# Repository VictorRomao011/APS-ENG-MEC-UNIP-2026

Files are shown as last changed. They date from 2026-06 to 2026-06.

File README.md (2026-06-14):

# APS Eng. Mecânica UNIP 2026 — Elevador em Escala Reduzida

🔗 **Tour virtual 3D (publicado):** https://victorromao011.github.io/APS-ENG-MEC-UNIP-2026/

> Atividade Prática Supervisionada (APS) — Engenharia Mecânica
> Universidade Paulista (UNIP) · Instituto de Ciências e Tecnologia (ICET) · Campus Jundiaí
> APS 2026/1 — **Equipe Altus**: *"Elevando segurança, precisão e inovação"*

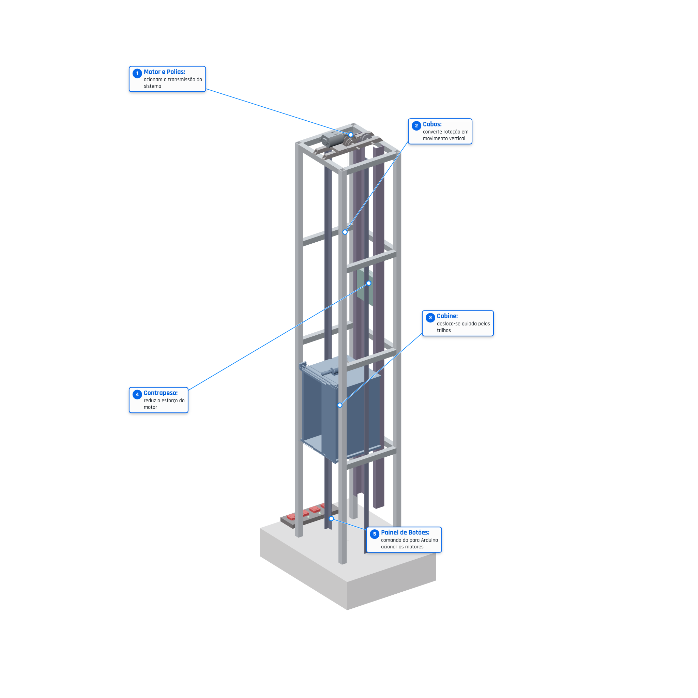
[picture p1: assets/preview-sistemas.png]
Elevador - sistemas principais


## Sobre o projeto

Protótipo funcional de **elevador em escala reduzida**, com transmissão por cabos, polias,
contrapeso e acionamento elétrico, totalmente modelado em ambiente 3D (FreeCAD) e
apresentado através de um **tour virtual interativo 360°** rodando direto no navegador
(Three.js), sem necessidade de instalar nenhum software de CAD.

O modelo é composto por **23 componentes principais**, com memorial técnico completo de
dimensionamento (estrutural, torque, potência, transmissão, cabos e estabilidade).

## Equipe Altus

- Victor Romão
- Gabriela Ferraz
- Mikael Campos
- Vitória Cristina
- Pedro Pelline
- Laura Casadei

## Tour virtual 3D

O arquivo `index.html` é um visualizador 3D autocontido (Three.js r128) que carrega a malha
do modelo CAD exportado do FreeCAD e permite:

- Rotação livre do modelo (orbit controls customizados) e vistas pré-definidas (Frontal,
  Lateral, Superior, Isométrica);
- Modo **explodido** (separa os componentes para visualizar a montagem);
- Modo com **medidas/cotas** sobre o modelo;
- Exportação de imagens em alta qualidade, incluindo a versão com **balões numerados**
  explicando os 5 sistemas principais (ver imagem acima).

> Como o `fetch`/carregamento da malha depende de ser servido via HTTP, o tour funciona
> publicado no GitHub Pages (link no topo) ou localmente via `python -m http.server`.
> Abrir o `index.html` com duplo clique (`file://`) pode não carregar corretamente.

## Sistema e funcionamento (5 subsistemas)

| # | Subsistema | Componentes do modelo | Função |
|---|---|---|---|
| 1 | **Motor e Polias** | Motor, Corona, Polia do Contrapeso, Eixo da Polia 01, Eixo da Polia 02, Viga das Polias | Aciona a transmissão do sistema |
| 2 | **Cabos** | Cabo da Cabine, Cabo do Contrapeso | Converte rotação em movimento vertical |
| 3 | **Cabine** | Cabine | Desloca-se guiada pelos trilhos (guias verticais) |
| 4 | **Contrapeso** | Contrapeso | Reduz o esforço exigido do motor |
| 5 | **Painel de Botões** | Painel de Botões, Botões, Leds, Comutador | Comando (Arduino) para acionar os motores |

## Modelo 3D — 23 componentes

Modelado em **FreeCAD** (`Ascensor5.FCStd`). Dimensões obtidas pela caixa envolvente (bounding
box) de cada peça do modelo 3D — usadas como base para o memorial de cálculo.

| Item | Componente | X — largura (mm) | Y — profund. (mm) | Z — altura (mm) | Acabamento/material |
|---|---|---|---|---|---|
| 01 | Base | 200.0 | 150.0 | 43.0 | concreto claro brilhante tipo LEGO |
| 02 | Painel de Botões | 28.0 | 81.0 | 6.0 | aço grafite brilhante |
| 03 | Botões | 12.8 | 68.7 | 8.4 | vermelho industrial brilhante |
| 04 | Leds | 3.6 | 61.0 | 8.4 | verde indicador brilhante |
| 05 | Comutador | 23.5 | 11.9 | 7.3 | metálico fosco/brilhante leve |
| 06 | Vigas Horizontais | 108.0 | 92.0 | 458.0 | alumínio brilhante |
| 07 | Viga Frontal | 92.0 | 8.0 | 8.0 | alumínio claro brilhante |
| 08 | Bancada | 37.0 | 16.0 | 4.0 | aço escovado brilhante leve |
| 09 | Motor | 20.0 | 50.0 | 15.0 | motor metálico real |
| 10 | Guias da Cabine | 92.0 | 7.0 | 600.0 | aço azulado brilhante |
| 11 | Guias do Contrapeso | 52.0 | 14.0 | 550.0 | aço técnico brilhante |
| 12 | Portas | 73.0 | 4.9 | 118.0 | azul industrial brilhante |
| 13 | Contrapeso | 48.0 | 10.0 | 54.8 | verde metálico brilhante |
| 14 | Cabo da Cabine | 2.1 | 10.9 | 335.0 | aço brilhante |
| 15 | GanchoCabina | 4.0 | 0.6 | 17.6 | aço polido |
| 16 | Corona | 14.0 | 26.4 | 26.4 | grafite brilhante |
| 17 | Verticales | 108.0 | 100.0 | 603.0 | alumínio estrutural brilhante |
| 18 | Cabine | 84.0 | 79.6 | 120.6 | azul industrial (igual às portas) |
| 19 | Cabo do Contrapeso | 1.9 | 35.6 | 199.7 | aço fosco brilhante leve |
| 20 | Polia do Contrapeso | 14.0 | 16.0 | 16.0 | polia metálica |
| 21 | Eixo da Polia 01 | 40.0 | 2.4 | 2.4 | cromado |
| 22 | Eixo da Polia 02 | 40.0 | 2.4 | 2.4 | cromado |
| 23 | Viga das Polias | 26.0 | 100.0 | 6.0 | aço estrutural brilhante |

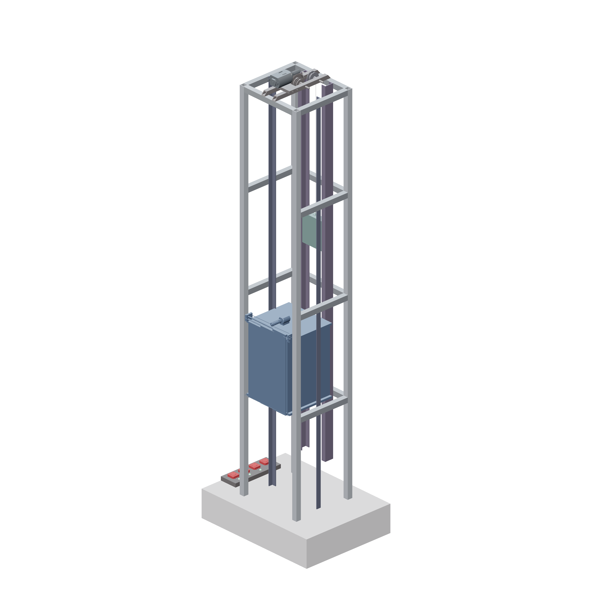
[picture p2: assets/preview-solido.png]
Vista sólida com os 23 componentes


## Memorial de cálculo — premissas e resultados

Memorial de cálculo estrutural e de desenvolvimento, usando as dimensões extraídas do
modelo 3D. Como o projeto acadêmico não informa massa real medida, potência do motor,
material definitivo e velocidade exigida, os resultados usam premissas técnicas
conservadoras para um prototipo em escala reduzida (fator de segurança = 2,0).

**Premissas adotadas**

| Parâmetro | Valor adotado | Justificativa |
|---|---|---|
| Unidade dimensional | milímetro (mm) | compatível com o modelo 3D |
| Gravidade (g) | 9,81 m/s² | valor padrão |
| Massa cabine estimada | 0,45 kg | cabine + portas em prototipo leve |
| Carga útil estimada | 0,30 kg | ensaio acadêmico em escala reduzida |
| Contrapeso projetado | 0,57 kg | cabine + 40% da carga útil |
| Velocidade de elevação | 0,05 m/s | movimento visível e seguro em bancada |
| Fator de segurança | 2,0 | prototipo didático |

**Resultados finais de dimensionamento**

| Grandeza calculada | Resultado | Observação |
|---|---|---|
| Massa total movida | 0,75 kg | cabine + carga útil |
| Contrapeso recomendado | 0,57 kg | cabine + 40% carga |
| Velocidade linear | 0,050 m/s | aprox. 3,0 m/min |
| Rotação da coroa/polia | 36,2 rpm | para D = 26,4 mm |
| Rendimento global | 73,7 % | polias + engrenagem + mancais |
| Torque de projeto | 0,063 N·m | com FS = 2 |
| Potência mínima calculada | 0,325 W | usar motor ≥ 1 W |
| Relação de engrenagens sugerida | 3,33:1 | z1 = 12 / z2 = 40 |
| Módulo sugerido | m = 1,0 mm | prototipo didático |
| Diâmetro mínimo do eixo | 2,00 mm | eixo existente ≈ 2,4 mm |
| Diâmetro mínimo do cabo | 0,61 mm | cabos existentes ≈ 1,9–2,1 mm |
| Flecha da viga das polias | 0,334 mm | baixa para prototipo |

**Modelo de balanceamento (contrapeso)**

```
m_total      = m_cabine + m_carga       = 0,45 + 0,30 = 0,75 kg
m_contrapeso = m_cabine + 0,40*m_carga  = 0,45 + 0,40*0,30 = 0,57 kg
Delta m      = m_total - m_contrapeso   = 0,18 kg
```

**Recomendações finais de desenvolvimento**

| Item | Recomendação |
|---|---|
| Motor | usar motor com redutor ou controle PWM, torque nominal ≥ 0,06 N·m no eixo de saída |
| Contrapeso | ajustar por ensaio até a cabine subir e descer sem trancos |
| Cabos | usar cabo/linha sem elasticidade excessiva e com boa fixação no gancho |
| Polias | alinhar eixos, evitar atrito lateral e cantos vivos no caminho do cabo |
| Guias | manter paralelismo; lixar ou polir pontos de contato da cabine |
| Base | aumentar massa da base ou fixar em bancada se houver vibração |
| Ensaio | testar sem carga, depois com carga progressiva de 50 g em 50 g |

> Conclusão: com as premissas adotadas, o sistema é viável como protótipo acadêmico em
> escala reduzida. O conjunto tem baixo torque exigido por causa do contrapeso, e os
> eixos/cabos representados no modelo possuem dimensões superiores aos mínimos calculados.
> A validação final depende de ensaio físico com as massas reais.

## Stack técnico

- **Modelagem 3D:** FreeCAD (`Ascensor5.FCStd`) — 23 objetos paramétricos (`Part::Feature`,
  `Part::Compound`, `Array`, `Sweep`, `Pad`, `Pocket`, `Chamfer`).
- **Visualização web:** Three.js r128 (via CDN), com malhas exportadas do FreeCAD e
  embutidas diretamente no `index.html` (sem dependência de arquivos externos `.stl`/`.gltf`).
- **Tour 360°:** controles de câmera customizados (Frontal/Lateral/Superior/Isométrica),
  modo explodido, anotações/medidas e exportação de imagens em alta resolução (PNG, com
  e sem balões explicativos).
- **Publicação:** GitHub Pages, servindo o `index.html` diretamente da branch `main`.

## Estrutura do repositório

| Arquivo | Função |
|---|---|
| `index.html` | Tour virtual 3D completo (HTML + CSS + JS + malha do modelo embutidos) |
| `assets/preview-sistemas.png` | Render do modelo com balões explicando os 5 subsistemas |
| `assets/preview-solido.png` | Render sólido do modelo completo (23 componentes) |
| `README.md` | Este arquivo |

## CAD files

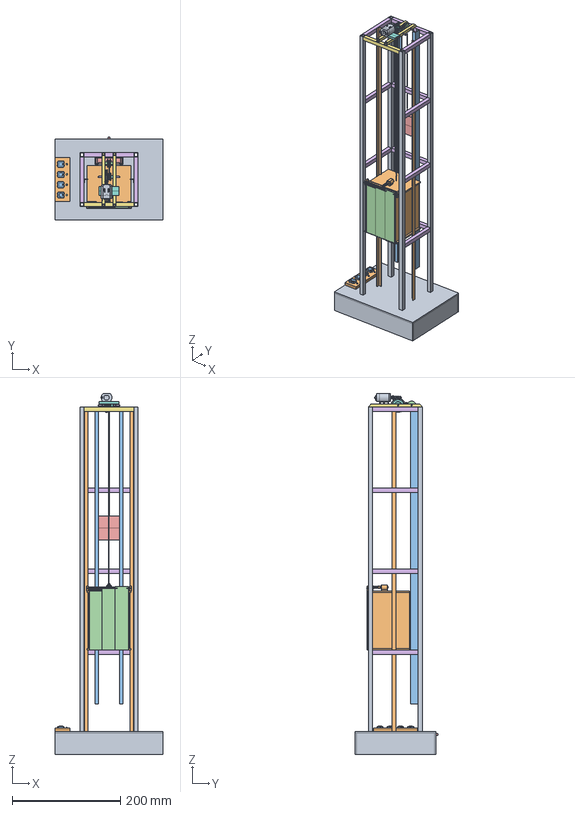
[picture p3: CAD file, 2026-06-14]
modelo-3d/Ascensor5.FCStd
200.0 x 154.0 x 668.0 mm
Base
Painel de Botões
Botões
Leds
Comutador
Vigas Horizontais
Viga Frontal
Bancada
Motor
Guias da Cabine
Guias do Contrapeso
Portas
Contrapeso
Cabo da Cabine
GanchoCabina
Corona
Verticales
Cabine
Cabo do Contrapeso
Polia do Contrapeso
Eixo da Polia01
Eixo da Polia 02
Viga das Polias

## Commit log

2026-05-16 freture: criando arquivo de index
2026-06-14 Detalha README com memorial de calculo, lista de 23 componentes e previews do modelo 3D
2026-06-14 Adiciona arquivo fonte FreeCAD (Ascensor5.FCStd) do modelo 3D
    [Ascensor5.FCStd]
